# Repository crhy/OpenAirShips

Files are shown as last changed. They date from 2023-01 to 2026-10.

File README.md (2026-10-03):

# OpenAirShips
Free Travel and Total Liberty for All Humanity

All relevant information is on http://OpenAirShips.com. Pop in and join the conversation on our Discord: https://discord.gg/wZ6nu7H

OpenAirShipsLogo

## Build it: the 1026 model, v0.2.1

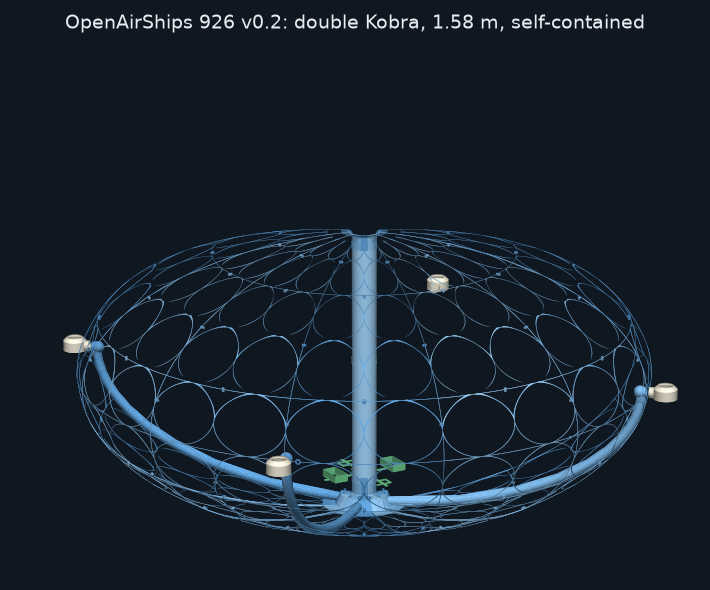
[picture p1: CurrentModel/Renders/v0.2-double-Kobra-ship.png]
OpenAirShips 1026 v0.2.1, double Kobra size, self-contained


The first buildable OpenAirShip is a 3D-printable model. It has a smooth ellipsoid hull of printed slices, a shrouded fan in a smooth central intake, and vectoring air-multiplier thrusters on the equator. Everything is open source.

### New in v0.2.1 (October 2026)
- **Flush fan housing:** each thrust duct now runs straight on from the fan housing, with no step inside or out. The ducts hug the hull curve all the way from the fan.
- **Lighter keel:** the ovals and diamonds now reach right up to the fan housing, so the hull is 4–7% lighter in every size.
- **Renamed 1026** for October 2026. The 926 files are in [`OldFiles`](OldFiles).
- **Corrected float numbers:** the v0.2 budget undercounted the double-Kobra hull (it measured 350 cm³ instead of 502). The figures below are the corrected ones, for the new, lighter hull.

### The double-Kobra build: it floats
The **double-Kobra build** is 1.58 m across. It carries its own battery and ESP32 controller and **floats on hydrogen alone**, for indoor flights in a garage or warehouse.
- **Hull:** 12 slices (4 left, 4 right, 4 plain). Each prints in 5 pieces on an Anycubic Kobra Max, and the intake shaft is two printed tubes.
- **Weight:** 977 g all-up in full-foam lightweight PLA with a 1500 mAh LiPo. Its 1022 L of hydrogen lifts 1145 g, so it has **168 g to spare**, and about 44 minutes of flight.
  - An 18650 pack gives 83 minutes, with 153 g to spare.
  - **Use full-foam LW-PLA:** in moderate foam it only just floats (+27 g with the LiPo, +12 g with the 18650 pack), and the 21700 pack makes it 93 g too heavy. See [FLOAT.md](CurrentModel/Analysis/FLOAT.md).
  - On helium (about 7% less lift) the full-foam LiPo build still floats, with about 84 g to spare.
- **Downloads:**
  - [Print files: 15 hull pieces + 2 intake tubes](CurrentModel/Print%20Files/v0.2.1%20double%20Kobra)
  - [Propulsion and avionics tray STLs](CurrentModel/CAD%20Files/Propulsion/4T/small/12s/x3.8/print)
  - [Build notes](CurrentModel/CAD%20Files/SimplifiedSlice/README.md#v02-double-kobra-build-x38-158-m-12-slices-in-pieces)
  - [Self-contained electronics](CurrentModel/Electronics/README.md#v02-self-contained-build-no-tether)
  - [BOM changes](CurrentModel/Electronics/BOM.md#v02-self-contained-double-kobra-build-changes-to-the-list-above)

### Bench and Kobra Max models (tethered)
| | 8 thrusters | 4 thrusters |
|---|---|---|
| **Bench size, 415 mm** (Prusa MK3S+) | [PieSlice1026-v0.2.1-8T.stl](CurrentModel/Print%20Files/PieSlice1026-v0.2.1-8T.stl), print 8 | [left](CurrentModel/Print%20Files/PieSlice1026-v0.2.1-4T-left.stl) and [right](CurrentModel/Print%20Files/PieSlice1026-v0.2.1-4T-right.stl), print 4 of each |
| **Kobra Max size, 790 mm** (Anycubic Kobra Max) | [PieSlice1026-v0.2.1-8T-KobraMax.stl](CurrentModel/Print%20Files/PieSlice1026-v0.2.1-8T-KobraMax.stl), print 8 | [left](CurrentModel/Print%20Files/PieSlice1026-v0.2.1-4T-left-KobraMax.stl) and [right](CurrentModel/Print%20Files/PieSlice1026-v0.2.1-4T-right-KobraMax.stl), print 4 of each |
| **Propulsion parts (STL)** | [bench](CurrentModel/CAD%20Files/Propulsion/print) · [Kobra Max](CurrentModel/CAD%20Files/Propulsion/x1.9/print) | [bench](CurrentModel/CAD%20Files/Propulsion/4T/print) · [Kobra Max](CurrentModel/CAD%20Files/Propulsion/4T/x1.9/print) |
| **Expected thrust** | ≈ 408 gf | ≈ 422 gf |

These don't float on hydrogen alone, but they can hover on their fan. The 4-thruster Kobra Max model in full-foam lightweight PLA (503 g, 124 L of hydrogen) has 55 g to spare, and the 4-thruster bench model in full foam (368 g) has 73 g.

| | |
|---|---|
| **CAD (FreeCAD, STEP, parametric Python)** | [Hull slices](CurrentModel/CAD%20Files/SimplifiedSlice) · [Propulsion](CurrentModel/CAD%20Files/Propulsion) |
| **Bill of materials** | [Electronics/BOM.md](CurrentModel/Electronics/BOM.md): about $230–320 for the core parts, with Amazon links, a lightweight-PLA option and the v0.2 changes |
| **Build notes** | [Hull slice](CurrentModel/CAD%20Files/SimplifiedSlice/README.md) · [Propulsion](CurrentModel/CAD%20Files/Propulsion/README.md) · [Electronics and firmware](CurrentModel/Electronics/README.md) |
| **Engineering** | [Will it float?](CurrentModel/Analysis/FLOAT.md) · [Airflow](CurrentModel/Analysis/AIRFLOW.md) · [Airflow, 4 thrusters](CurrentModel/Analysis/AIRFLOW-4T.md) · [Design constraints](CurrentModel/DESIGN-CONSTRAINTS.md) · [Open questions](CurrentModel/OPEN-QUESTIONS.md) |
| **Changelog** | [v0 → 1026 v0.2.1](CurrentModel/CHANGELOG.md) |

<p>
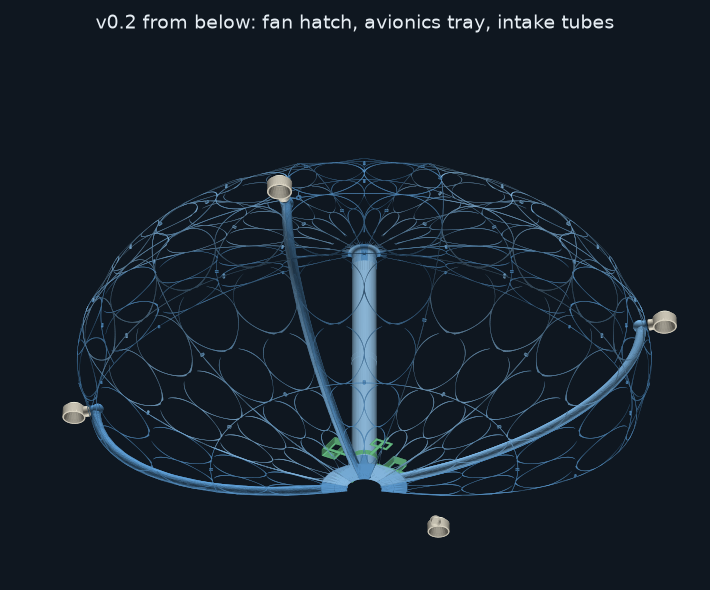
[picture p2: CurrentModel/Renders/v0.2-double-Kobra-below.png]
v0.2 from below: fan hatch, avionics tray, intake tubes

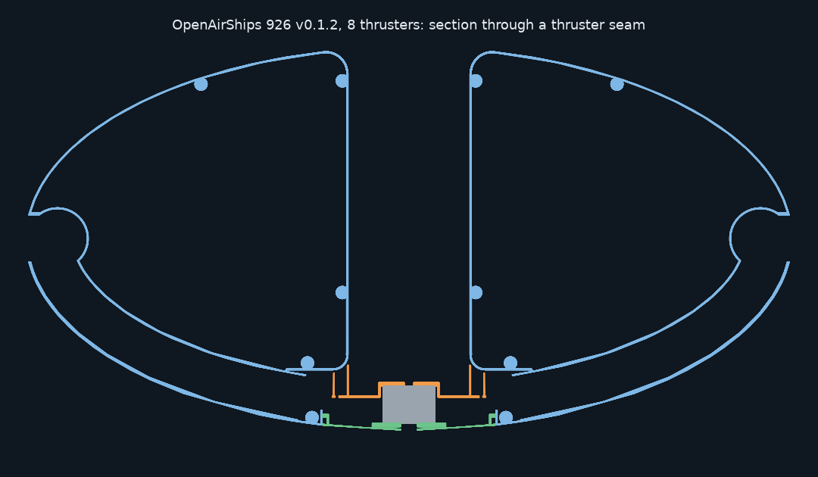
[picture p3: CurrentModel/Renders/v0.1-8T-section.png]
8 thrusters, section through a seam

</p>

**At a glance**
- **Hull:** 0.86 mm airtight walls. The outside is a smooth ellipsoid, and it's lattice everywhere except the air path. The intake is Ø66 from the bellmouth down to the fan.
- **Fan:** a 2207 1750 KV motor on 4S drives an 88 mm PETG impeller, and the hull's housing wall is its shroud. It comes out through a bayonet hatch in the keel.
- **Thrusters:** 8 or 4, each swivelling ±90° on a micro servo, exactly on the equator.
- **Control:** an ESP32 with a Wi-Fi control page and a link-loss failsafe. It drives a PCA9685 on the bench models, or the servos and ESC directly on v0.2, with a battery monitor.

## Repository layout
| Folder | What's in it |
|---|---|
| [`CurrentModel/`](CurrentModel) | **The current buildable model (1026 v0.2.1):** CAD, print files, propulsion, electronics, firmware, analysis and [changelog](CurrentModel/CHANGELOG.md) |
| [`web/`](web) | Source for [OpenAirShips.com](http://OpenAirShips.com) (static site on Cloudflare) |
| [`docs/`](docs) | Project notes: website deployment and content audit, the Unreal diagnostic report |
| [`WhitePaper/`](WhitePaper) | Whitepaper and builder guide |
| [`Art/`](Art), [`vidz/`](vidz) | Logos, concept art and concept videos |
| [`WebSnap2024/`](WebSnap2024) | PDFs of the 2024 website |
| [`OldFiles/`](OldFiles) | Earlier models and print files, kept for history |

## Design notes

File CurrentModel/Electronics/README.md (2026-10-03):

# Electronics: 1026 model (tethered bench demo and self-contained build)

- **Parts list:** [BOM.md](BOM.md), with Amazon links.
- **Firmware:** [`firmware/airship_bench`](firmware/airship_bench).

## Wiring

```mermaid
flowchart LR
  PSU["4S LiPo 1500 mAh (or 15 V 350 W supply)"] -->|"+14.8 V"| FUSE["30 A inline fuse"]
  FUSE -->|"≤ 30 cm, 12 AWG"| XT["XT60 on the ship"]
  XT --> ESC["45 A BLHeli_S ESC"]
  XT --> UBEC["5 V 5 A UBEC"]
  ESC -->|"3 phase wires"| MOTOR["2207 1750 KV + impeller"]
  ESC -->|"BEC 5 V + GND"| ESP["ESP32 DevKitC: 5V / GND pins"]
  UBEC -->|"5 V servo rail"| PCA["PCA9685: V+ terminal"]
  ESP -->|"3V3 -> VCC, GPIO21 -> SDA, GPIO22 -> SCL, GND"| PCA
  PCA -->|"ch 0-7"| SERVOS["8 x MG90S swivel servos"]
  PCA -->|"ch 8, signal + GND only"| ESC
```

- **Common ground:** tie together the grounds of the ESC, the UBEC, the ESP32 and the PCA9685.
- **ESC red wire:** pull the red (BEC +5 V) pin out of the ESC's signal plug before it goes on PCA9685 channel 8. The ESC's BEC powers the ESP32 through separate leads, and the red wire would otherwise feed into the servo rail.
- **Separate supplies:** the servos run from the UBEC. The ESP32 and the PCA9685 logic run from the ESC's BEC, so servo stalls can't brown out the ESP32.
- **Thruster numbering:** thruster *i* is on seam *i*, at azimuth 22.5° + 45° × *i*, counter-clockwise from +X seen from above. It plugs into PCA9685 channel *i*.
- **Wire routing:**
  - **Motor wires:** nothing may cross the intake shaft. The three phase wires leave through the Ø6 hole in the fan hatch. Seal the hole around the wires (hot glue or silicone, so the hatch can still come off).
  - **Motor direction:** the impeller must turn **counter-clockwise seen from above**. The bayonet hatch also relies on that direction to stay locked. If it runs the wrong way, swap any two motor wires.
  - **Servo leads:** the servos sit inside the hull, between the skin and the shaft. That space isn't part of the air path, so run the leads along the ribs and out through a lower lattice window to the electronics on the bench.
  - **Electronics:** for the tethered bench demo the ESP32, PCA9685 and UBEC ride on the bench, not in the ship; there are no decks in the bench model. The ESC sits on the test stand just under the keel, next to the hatch, so the phase wires stay short.
  - **Battery leads:** keep the battery within about 30 cm of the ESC. For a longer tether, solder a 470 µF / 35 V low-ESR capacitor across the ESC's power input.

## Power budget

| Load | Typical | Peak |
|---|---|---|
| Fan (2207 1750 KV + 88 mm impeller) | ~75 W at the firmware's 60 % cap | ~340 W (~25 A at 14.8 V) at full throttle |
| 8 × MG90S | 1–1.5 A at 5 V | 5.6 A at 5 V if all stall (the UBEC limits this) |
| ESP32 + PCA9685 | 0.25 A at 5 V | 0.5 A |

- **Power source:** a 4S LiPo (1300–1800 mAh, 75C or better) is the simplest source that handles 25 A. At full throttle it runs about 3 minutes, which is plenty for thrust runs.
- **Mains alternative:** a 15 V 350 W supply (≈23 A). Keep the firmware's `THROTTLE_LIMIT` at 0.9 or below with it.
- **Don't use 12 V:** the fan needs about 15,700 rpm, and a 1750 KV motor only reaches that on 4S (see [../Analysis/AIRFLOW.md](../Analysis/AIRFLOW.md)).

## v0.2 self-contained build (no tether)
The double-Kobra build carries everything on the avionics tray, above the fan housing and outside the gas cells. The parts are in [BOM.md](BOM.md) (items S1–S9).

```mermaid
flowchart LR
  BAT["2 x 2S 18650 packs in series (4S, 2.8 Ah), or a 4S LiPo 1500"] --> SW["power switch / XT30 loop key"]
  SW --> ESC["30 A ESC"]
  SW --> BEC["3 A BEC, 5 V"]
  SW -->|"100k / 22k divider"| ADC["ESP32 GPIO 34"]
  ESC --> MOTOR["2207 motor + impeller"]
  BEC --> ESP["ESP32 5V pin"]
  BEC --> SERVOS["4 x SG90 (5 V)"]
  ESP -->|"GPIO 25, 26, 27, 14"| SERVOS
  ESP -->|"GPIO 13, signal + GND"| ESC
  ESP -->|"I2C 21 / 22"| IMU["GY-91 IMU + baro"]
```

- **Firmware:** before building `airship_bench.ino`, add these three lines at its top:
  ```
  #define OAS_DIRECT_PWM
  #define OAS_THRUSTERS 4
  #define OAS_FIRST_AZ_DEG 15.0f
  ```
  - The ESP32 then drives the servos (GPIO 25, 26, 27, 14 for thrusters 0–3) and the ESC (GPIO 13) itself at 50 Hz, with no PCA9685.
  - The thrusters are on the left/right seams at 15°, 105°, 195° and 285°.
- **Battery monitor:** a 100 kΩ / 22 kΩ divider from the battery + to GPIO 34 (and GND).
  - Below 3.4 V per cell the firmware stops the fan and centres the servos, and it stays stopped until reset.
  - The control page shows the pack voltage.
- **ESC red wire:** as on the bench, pull it from the ESC's signal plug. The BEC powers the ESP32 and servos.
- **Wiring:** run the leads along the ribs outside the gas cells. Nothing crosses the intake tubes.
- **Hydrogen indoors:**
  - Keep every connector and switch outside the gas cells, and fill and vent the cells outdoors or with good ventilation.
  - **Helium works too:** it lifts about 7% less, 1061 g instead of 1145 g. The full-foam build with the LiPo still floats on it, with about 84 g to spare.
- **Flight time:** 44 min on the 1500 mAh LiPo, 83 min on the 18650 pack, at 24 W average. See [FLOAT.md](../Analysis/FLOAT.md).

## Bench bring-up
1. **Flash the firmware.**
   - Install the ESP32 board package and the "Adafruit PWM Servo Driver Library".
   - Open `firmware/airship_bench/airship_bench.ino` and flash it to the "ESP32 Dev Module".
2. **Check the servos with the impeller off.**
   - Join Wi-Fi "OpenAirShip" (the password is in the sketch; change it) and open http://192.168.4.1.
   - All 8 servos should centre, with lift at +1 and every jet pointing down.
   - Move the Yaw slider: every thruster should tilt the same way.
   - Set per-servo trim in `SERVO_TRIM_DEG`.
3. **Calibrate the ESC (impeller off).** Follow its manual: throttle high at power-on, then low. The firmware sends 1000–2000 µs.
4. **First spin (impeller on).**
   - Press ARM and raise the throttle slowly.
   - The firmware caps the throttle at 60 % (`THROTTLE_LIMIT`) until the impeller has been spun up and checked.
   - The fan stops on STOP, or within 1 s if the page loses its link.
5. **Measure.**
   - Put the ship on a kitchen scale: the weight drop is the lift.
   - With the optional sensors (BOM items 17–18), log plenum pressure and power against throttle.

## Firmware
- **`mixer.h`:** turns lift, surge, sway and yaw commands into swivel angles, for 8 thrusters or (with `OAS_THRUSTERS 4`) 4. All thrusters share one scale, so a yaw command gives no surge or sway. Every thruster pushes with about the same force because they share one fan, so the mixer steers direction only; the throttle sets magnitude.
- **Host test:** `g++ -std=c++17 -Iairship_bench test/test_mixer.cpp && ./a.out`, run from `firmware/`. It checks pure lift, yaw, surge, sway, the ±90° limits and the servo pulses. All of these pass.
- **`airship_bench.ino`:** the Wi-Fi access point, the control page, ESC arming and the link-loss failsafe. It has been compiled on a PC against stand-ins for the Arduino APIs, **but not yet built or run on a real ESP32**.

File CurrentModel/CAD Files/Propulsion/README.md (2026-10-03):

# Propulsion: shrouded fan, thrust ducts and air-multiplier thrusters (1026 v0.2.1)

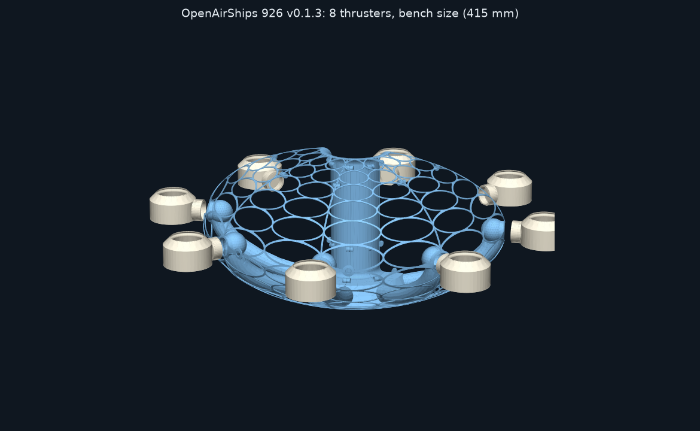
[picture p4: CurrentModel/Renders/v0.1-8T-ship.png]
8 thrusters

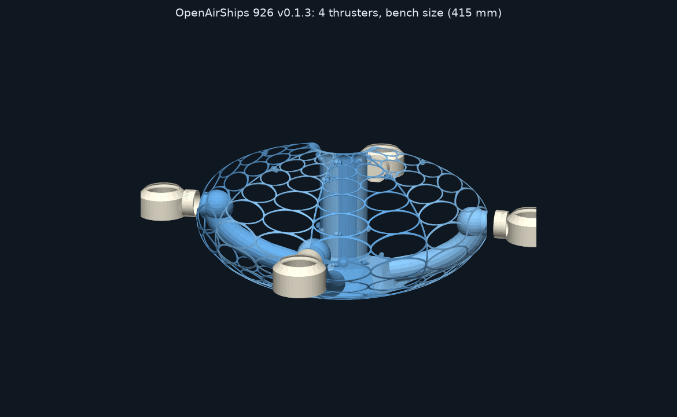
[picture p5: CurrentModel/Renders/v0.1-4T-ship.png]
4 thrusters

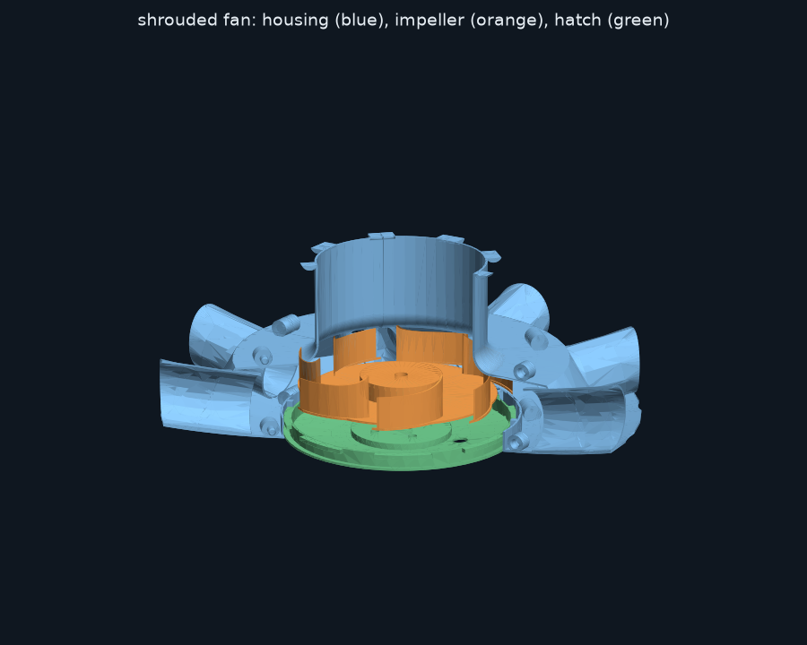
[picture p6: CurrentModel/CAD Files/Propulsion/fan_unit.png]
shrouded fan unit

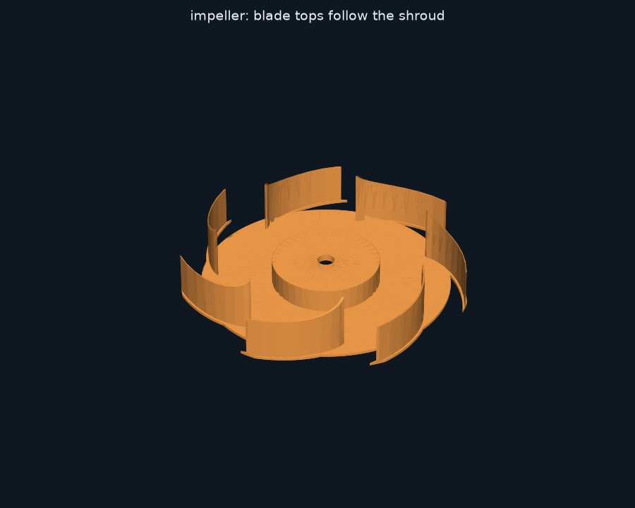
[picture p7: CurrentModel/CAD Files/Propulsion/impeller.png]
impeller

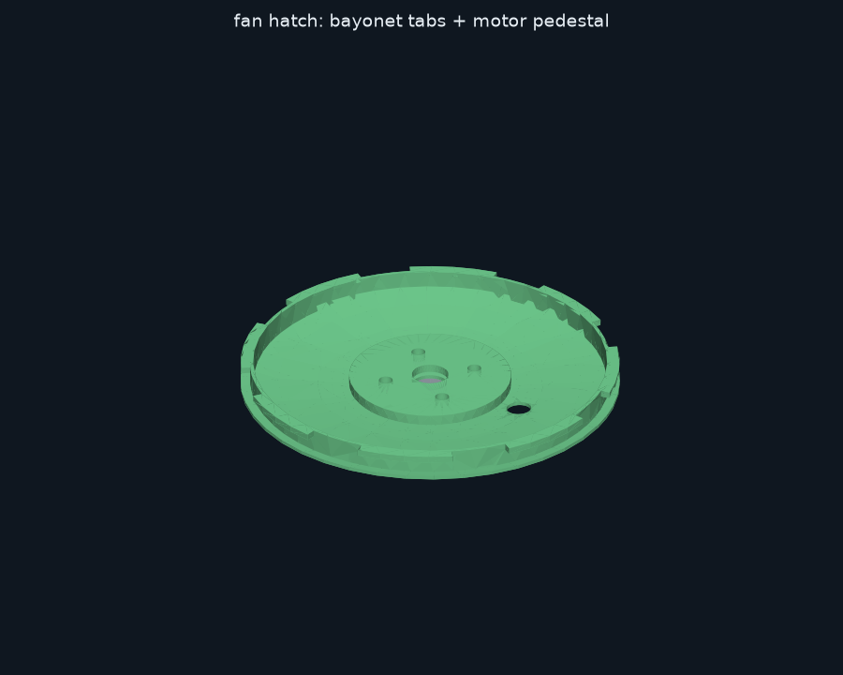
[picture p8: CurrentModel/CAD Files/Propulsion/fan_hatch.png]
fan hatch

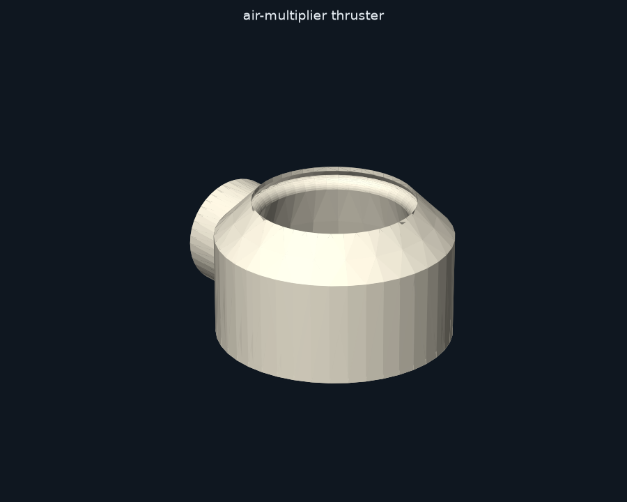
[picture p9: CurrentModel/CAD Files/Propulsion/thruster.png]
thruster


## Versions
The same parametric source (`propulsion.py`) builds the parts for every hull version. Set the version with `OAS_VARIANT=8T|4T` and `OAS_SCALE=1|1.9`, as for the slices.

| Version | Folder | Thrusters | Duct / stem | Ring | Gears | Expected thrust |
|---|---|---|---|---|---|---|
| 8 thrusters, bench | `.` (this folder) | 8 | Ø24 / Ø25-22 | 64 mm OD, 1.6 mm slot | 36T m1 | ≈ 408 gf |
| 4 thrusters, bench | `4T/` | 4 | Ø34 / Ø34-31 | 69 mm OD, 2.0 mm slot (same profile as 8T) | 44T m1 | ≈ 422 gf |
| 8 thrusters, Kobra Max | `x1.9/` | 8 | as 8T | as 8T | as 8T | ≈ 401 gf |
| 4 thrusters, Kobra Max | `4T/x1.9/` | 4 | as 4T | as 4T | as 4T | ≈ 418 gf |
| **v0.2 double Kobra** (x3.8, 12 slices) | `4T/small/12s/x3.8/` | 4 | as 8T (Ø24 / Ø25-22) | as 8T | as 8T | ≈ 306 gf |

- **4 thrusters:** each duct carries twice the flow, so the ducts, stems and rings are sized up to keep the air speeds down (see [AIRFLOW-4T.md](../../Analysis/AIRFLOW-4T.md)). Otherwise the parts and the assembly are the same as for 8 thrusters, with half as many.
- **Kobra Max size:** the fan, thrusters and servos keep their size. Only the hull grows, so the servo mount and fan hatch follow the flatter hull curve, and the ducts get longer.
- **v0.2 double Kobra:** 4 thrusters with the 8-thruster hardware, SG90 servos, a 12-tab fan hatch and the **avionics tray** (`avionics_tray.step`, 24 cm³).
  - **Tray:** a ring clamps round the lower intake tube just above the fan housing, with 4 arms reaching out between the ducts. Two arms carry battery cradles (40 × 70 × 20 mm, one 2S pack each, opposite each other for balance). The other two carry plates for the ESC, ESP32, BEC and IMU.
  - **Why the fan and ducts aren't scaled up:** the ship floats on hydrogen, so the fan only manoeuvres it. 306 gf moves the 1.58 m hull at about 2.5 m/s, which is plenty indoors. The 4-thruster Ø34 ducts would add about 60 g of duct wall. A bigger fan would add more again: motor, ESC, battery current and a wider shaft.
  - **To scale it up later:** set `OAS_THRUSTER=L` for the Ø34 ducts, stems and 69 mm rings. The fan is set by `IMP_R` / `SHAFT_R`.
  - Build it with the v0.2 settings in the slice README, plus `python3 propulsion.py`.
- **Assembly:** a 4-thruster hull alternates left and right slices. Each left/right pair closes one duct, and its right slice carries the servo hole.

## How the air moves
1. The impeller pulls air in over the bellmouth at the top of the hull and **down the smooth central shaft**. Nothing sits in the shaft: the motor stands on the fan hatch in the keel, under the impeller.
2. The shaft is the impeller eye's diameter (Ø66) all the way down. At the bottom the hull's own housing wall curves over the blade tips with 1.5 mm clearance, so the **housing acts as the fan's shroud**. The impeller throws the air outward into the housing, and it can't leak back up the shaft.
3. The housing feeds the **8 thrust ducts**, which run *inside* the skin to the equator. The hull's outside stays smooth.
4. At each thruster seam a rotating **stem** passes through a round hole in the skin. Its flange sits behind a bearing sleeve inside the duct, and it carries a printed **air-multiplier ring** with a Coanda lip and a 1.6 mm slot (2.0 mm on 4 thrusters).
5. An MG90S servo **inside the hull** turns the stem through a 1:1 pair of 36-tooth gears just outside the skin, giving ±90° of travel. The thrusters sit exactly on the equator. Their swivel axis is radial, so each jet can point anywhere between up/down and sideways along the hull. Together the thrusters give lift, yaw, surge and sway.

Expected thrust (8 thrusters): **about 4.0 N (≈ 410 gf)** at 15,650 rpm, 62 L/s. The range is 306–564 gf depending on the fan efficiency and air-multiplier gain measured on the bench; see [../../Analysis/AIRFLOW.md](../../Analysis/AIRFLOW.md).

## Parts
Print from the version's `print/*.stl`. Each file is already posed for printing: 0.2 mm layers, 0.4 mm nozzle. The table gives the 8-thruster bench sizes; 4-thruster rings are 19.8 cm³, stems 4.9, gears 2.4 and 4.8, and the fan hatch 11.3.

| Part | Qty | cm³ each | Print notes |
|---|---|---|---|
| `impeller` | 1 | 6.2 | **PETG**; the tip runs at 72 m/s. Backplate on the bed; no supports, as the cup top bridges 31 mm. Backward-curved rotor, 88 mm, 7 blades, sized by the airflow analysis: eye Ø66, exit width 12.5 mm. The blade tops follow the housing's shroud curve. Lightened: 0.8 mm backplate, 0.86 mm blades, scalloped rim. A 0.86 mm **cup** fits over the motor bell, and its 2 mm top disc is clamped between the bell and the M5 prop nut. About 8 g. Balanced by design; still check it on a pencil. |
| `fan_hatch` | 1 | 10.1 | The keel under the fan, removable. Dish down; use **supports on build plate only**, since the dish's outside is part of the hull curve and rises 2.7 mm at the rim. It carries the motor pedestal (4 × M3 × 6, 16 × 16 mm, screwed from below), a spigot wall, 8 bayonet tabs and a Ø6 wire hole. |
| `servo_mount` | 8 | 4.3 | Plate down; no supports. Epoxy it to the inside of the skin, centred on the Ø8 servo hole. The servo drops in with its spline outward and is held by two M2 screws driven from inside the hull. |
| `stem` | 8 | 3.6 | Flange down; no supports. Put it into the stem hole from inside the half-duct **before** joining the neighbouring slice. Wrap it in PTFE tape. |
| `stem_gear` | 8 | 2.1 | Flat. Glue it on the stem's D-flat. |
| `servo_gear` | 8 | 3.8 | Hub down. Its hub reaches through the Ø8 skin hole onto the servo spline. Glue it and fix it with the servo's horn screw from outside. |
| `thruster_ring` | 8 | 14.1 | Exit down, axis vertical; no supports. Every surface faces up or overhangs 45° or less. Check the 1.6 mm slot is clear; a 1.5 mm shim works. |

- **Total printed propulsion:** about 233 cm³ (≈ 290 g of PLA) for 8 thrusters, or 154 cm³ (≈ 190 g) for 4, plus the PETG impeller (≈ 8 g). Lightweight PLA for the rings and servo mounts saves about a third of theirs; see [FLOAT.md](../../Analysis/FLOAT.md).
- **Motor:** 2207 1750 KV on 4S (≈ 32 g, ≈ 25 A at full throttle). It must spin **counter-clockwise seen from above**; swap any two motor wires if it doesn't.
- **Parametric source:** `propulsion.py`. All dimensions are at the top.
- **Fit checks:** `check_fit.py` runs 35 checks against the assembled hull, and they all pass for all four versions. They cover:
  - the impeller under the shroud (≥ 1.2 mm clearance) and its path up through the hatch opening
  - the hatch at its insert angle, at 5–15 mm below seated, and locked
  - the motor and prop nut, the stems, the servos and their mounts, the gears
  - the rings at −90…+90°, including against the neighbouring thruster

## The fan hatch (bayonet)
- Each slice carries a lug and a stop post on the ring wall round the keel opening. The hatch has 8 tabs.
- **To fit it:** turn the hatch so its tabs sit on the seams (between the lugs), push it up flush, then **turn it 11.5° clockwise (seen from above)** until the tabs hit the stop posts.
- **What holds it:**
  - The housing pressure (≈ 1,900 Pa, about 13 N on the hatch) presses the tabs down onto the lugs.
  - The motor's reaction torque is clockwise, so it pushes the tabs against the posts. The hatch can't unscrew itself while the fan runs.
- **Seal:** run a strip of tape round the outside seam.

## Assembly order
1. **Slices.** Epoxy the seams of the shaft and contraction, the housing wall, the keel round the hatch ring, and the ducts, so they are airtight.
2. **Stems and servo mounts, while the slices are still apart.**
   - Put each stem into its stem hole from inside the open half-duct, then join and epoxy the neighbouring slice. This closes the duct and traps the stem's flange behind the boss.
   - Epoxy each servo mount inside the skin over its Ø8 hole. Drop the servo in and screw it from inside.
3. **Gears and rings.**
   - Centre the servos (the firmware centres every servo at boot).
   - Mesh the gears with the ring's exit pointing **down**, then glue the ring onto the stem.
4. **Fan unit** (any time after assembly, and removable for service).
   - Bolt the 2207 to the hatch's pedestal (4 × M3 × 6 from below). Pass its wires through the Ø6 hole and seal the hole around them.
   - Put the impeller on the motor shaft: its cup sits on the bell. Fix it with the M5 prop nut and trim any shaft past the nut.
   - Offer the whole unit up through the keel opening and lock the bayonet (above). The blade tops then run 1.5 mm under the shroud.
   - This relies on the motor measuring 20 mm from mount face to bell top (`MOTOR_L`). Shim under the motor, or change `MOTOR_L` and reprint, if yours differs.
5. Wire it up as in [../../Electronics/README.md](../../Electronics/README.md).

## Known limits (to bench-test)
- **Fan efficiency:** the analysis assumes 0.42 for the shrouded housing, against 0.35 for an open impeller. Measure housing pressure and motor power against throttle and put the result into `airflow.py`. The scalloped rim lets a little air fall back into the blade passages; if pressure comes out low, try `IMP_SCALLOP_R = 44` (no scallops, +3.5 g).
- **Motor cooling:** the 2207 sits under the impeller, in the housing's airflow. Check it's warm, not hot, after a full-throttle run.
- **Swivel seal:** it's a plain bore through the skin and sleeve, with PTFE tape, and some leakage is expected. Measure it before adding an O-ring.
- **Servo height:** it depends on your MG90S. If the gear hub doesn't reach the spline, shim under the servo's tabs.
- **Air-multiplier slot:** 1.6 mm is the analysis optimum for this fan within the 75 m/s tip-speed limit. Try 1.4 or 1.8 mm (`SLOT`) and compare thrust on the scale.

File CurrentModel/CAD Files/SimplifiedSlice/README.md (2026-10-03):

# Airship pie slice 1026 (v0.2.1): 8- and 4-thruster designs, bench, Kobra Max and double-Kobra sizes

One 45° slice of the hull; eight of them plug together into the full ship. The source is one parametric file that builds every version:

| Version | Slices | Print file (in `Print Files/`) | Size | Printer |
|---|---|---|---|---|
| **8 thrusters, bench** | 8 identical | `PieSlice1026-v0.2.1-8T.stl` | 415 mm across | Prusa MK3S+ (or any 210 × 210 mm bed) |
| **4 thrusters, bench** | 4 left + 4 right, alternating | `PieSlice1026-v0.2.1-4T-left.stl`, `…-4T-right.stl` | 415 mm | Prusa MK3S+ |
| **8 thrusters, Kobra Max** | 8 identical | `PieSlice1026-v0.2.1-8T-KobraMax.stl` | 790 mm | Anycubic Kobra Max (400 × 400 × 450 mm) |
| **4 thrusters, Kobra Max** | 4 left + 4 right | `PieSlice1026-v0.2.1-4T-left-KobraMax.stl`, `…-right-KobraMax.stl` | 790 mm | Kobra Max |

It keeps the outline of `OldFiles/CAD/airship pie slice 125.FCStd` (archived at the repository root): the 207.765 × 104 mm ellipse, rebuilt as clean parametric geometry. See [../../DESIGN-CONSTRAINTS.md](../../DESIGN-CONSTRAINTS.md) for the fixed rules and [../../Analysis/FLOAT.md](../../Analysis/FLOAT.md) for weights, hydrogen volume and lift.

8 thrusters: section through a seam
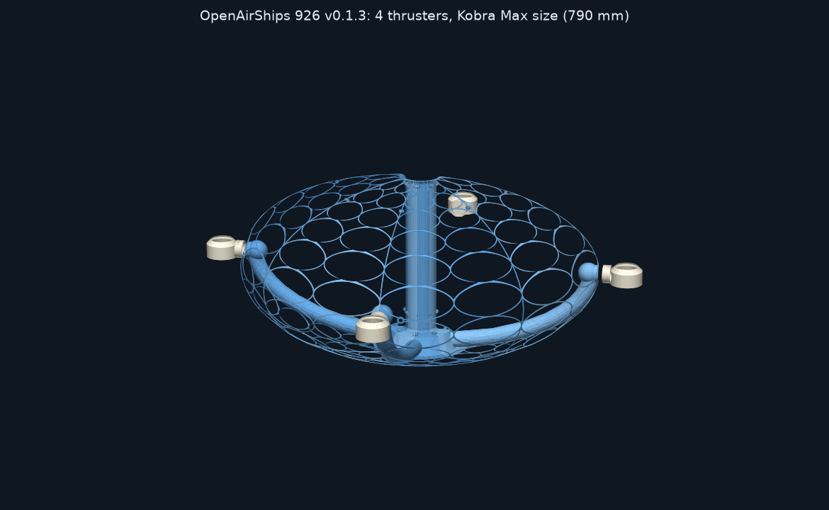
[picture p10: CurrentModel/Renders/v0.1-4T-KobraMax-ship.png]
4 thrusters, Kobra Max size

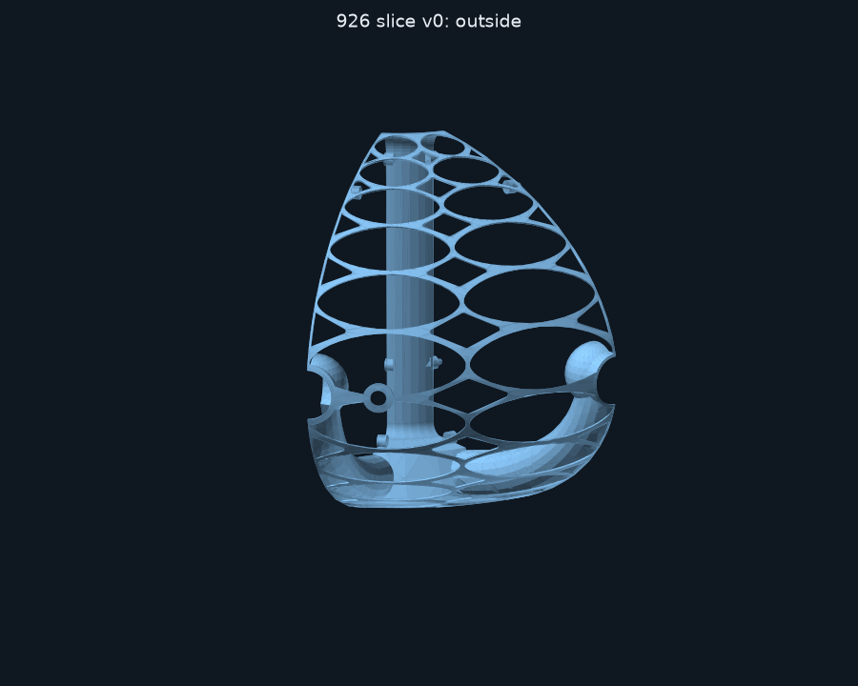
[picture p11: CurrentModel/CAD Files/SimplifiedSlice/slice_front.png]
slice, outside

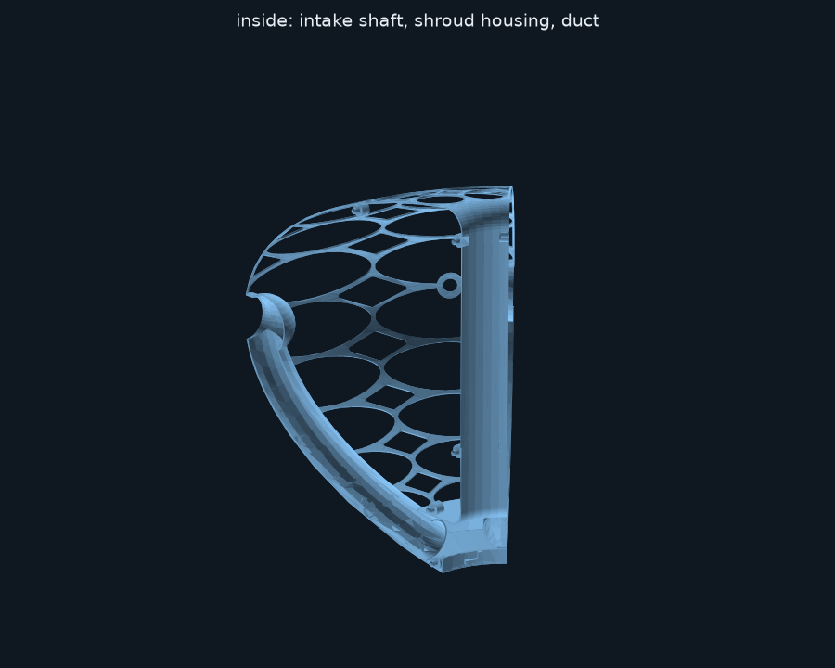
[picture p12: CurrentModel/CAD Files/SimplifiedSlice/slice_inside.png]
slice, inside

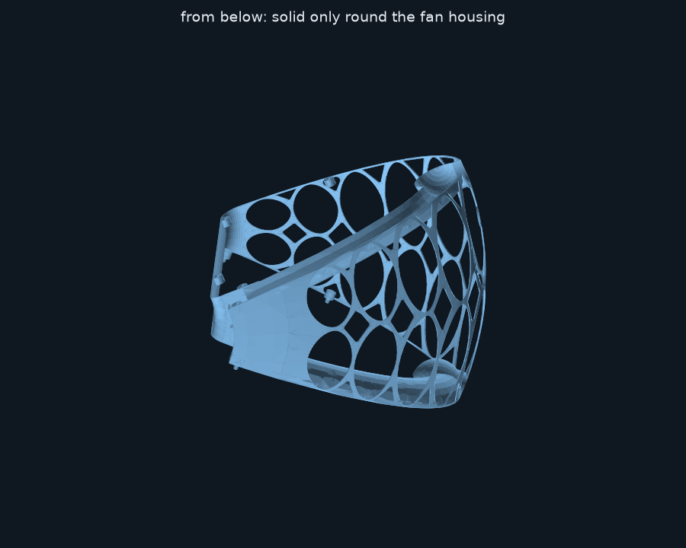
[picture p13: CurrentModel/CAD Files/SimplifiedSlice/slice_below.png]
slice from below


## What's in a slice
- **Skin:** a smooth ellipsoid outside. The skin runs in one arc from the keel up over the top and **rolls into the intake shaft over a 12 mm bellmouth**.
- **Intake shaft:** a plain 0.86 mm tube, **Ø66 all the way from the bellmouth down to the impeller eye.** Nothing is inside it: no ledge, no spider, no windows. It must stay solid and smooth for the craft's Coanda intake flow.
  - Up to v0 the shaft was Ø95 and narrowed at the bottom. That width was only needed to drop the impeller in from the top, and it now comes in through the keel hatch.
  - The narrower shaft costs about 1% of the fan pressure and gives the gas cells about 0.6 L more room.
- **Shrouded fan housing:** the housing *is* the fan's shroud.
  - At the bottom of the shaft the wall turns from axial to radial over the blade tips, with 1.5 mm clearance, and runs out flat as the housing ceiling. That's z = −71.3 for 8 thrusters, or 10 mm higher for 4 thrusters so the bigger duct mouths fit.
  - Past the blade tips the ceiling eases down to meet the ducts' tops at their mouths. The outer wall stands just past the mouths, at r = 60.5, and drops straight to the keel.
  - The keel skin is the housing's floor. Each duct hugs the hull curve from its mouth, so **it runs straight on from the housing, flush top and bottom**, with no step for the air to trip over (since v0.2.1).
  - The housing holds the impeller (r 44) and the duct mouths (r ≈ 57–60). **The keel is solid only under this housing**; from its outer wall outward it's lattice.
- **Fan hatch opening:** the keel under the fan is a Ø94 opening that the impeller and motor come in and out through. A ring wall round it carries this slice's **bayonet lug** and **stop post**. The removable `fan_hatch` (see `../Propulsion`) locks onto the 8 lugs.
- **Ducts:** they run *inside* the skin, at a constant depth along the hull curve, from their mouths in the fan housing up to the equator, where each ends in a bulb behind the stem hole and its bearing sleeve. Each duct is split by a seam plane, so two slices close it. Their own 0.86 mm walls keep them airtight; the lattice runs straight over them.
  - **8 thrusters:** Ø24 ducts on every seam, a Ø32 bulb and a Ø25.4 stem hole.
  - **4 thrusters:** Ø34 ducts on every other seam (twice the flow each), a Ø44 bulb and a Ø34.4 stem hole. A **left** slice carries its half-duct on its +22.5° seam; a **right** slice carries it on its −22.5° seam, plus the servo hole. Assemble them alternating, left, right, left, right, so each pair closes one duct.
- **Lattice:** everything else is structure only.
  - Two columns of large oval cells, with 2.0 mm ribs.
  - **Every row is the same length along the skin:** five rows from the fan housing up to the equator, six above it (about 33 mm at bench size and 73 mm at Kobra Max size). All the cells therefore have the same proportions, top and bottom.
  - A **ring rib on the equator (z = 0)** carries the thruster stem and servo holes. Thrusters stay exactly on the equator, for navigation.
  - **Minimum material:** the ovals are laid out on the real curved skin, so each fills its cell, touching all four rib lines. Every junction where ovals meet is a hollow window that takes *all* the skin more than 2 mm from the ovals, including along the first and last rows. What's left is a web of 2.0 mm ribs everywhere, and nothing thicker.
  - **Seams:** on the seams each slice's junction windows stop at a continuous 1 mm edge strip, so the two slices' strips glue into one full rib.
- **Joints:** 5 bosses along each seam, all at the same (r, z) positions. The +22.5° seam has Ø3 × 3.6 mm pegs and the −22.5° seam has Ø3.3 × 4.2 mm holes, both with 0.4 mm chamfers.

## Kobra Max size (x1.9)
- **What grows:** only the hull outline and its lattice cells grow 1.9×, to 790 mm across.
- **What stays the same size:** walls (0.86 mm), ribs (2 mm), joints, the fan, the ducts, the thrusters and the servos.
- **Why not just scale the STL:** printed mass grows about as size^1.3 while the hydrogen volume grows as size³ (124 L instead of 16 L). Scaling the STL uniformly would thicken every wall too, and the ratio would never improve.
- **Print volume:** each slice lies on its seam, 372 × 393 × 279 mm. That fits the Kobra Max's 400 × 400 × 450 mm with about 3 mm to spare each side, so **use a skirt, not a brim**, or rotate the part a few degrees on the bed.

## v0.2 double-Kobra build (x3.8, 1.58 m, 12 slices in pieces)
The self-contained build that floats on hydrogen alone. See [FLOAT.md](../../Analysis/FLOAT.md) for its weight, lift and flight time.

double-Kobra build

- **12 slices of 30°, 4 thrusters.**
  - **Left** and **right** slices each carry half a thrust duct; **plain** slices have none.
  - Go round the ship **left, right, plain**, four times.
  - Print 4 of each type.
- **Pieces:** each slice is cut into 5 pieces that fit a Kobra Max (400 × 400 × 450 mm):

  | Piece | Where | Print size (mm) |
  |---|---|---|
  | `middle` | the band z = ±150 mm round the equator, with the thruster stem hole | 187 × 307 × 395 (left), 158 × 307 × 395 |
  | `top-outer`, `bottom-outer` | the top/bottom band outside r = 415 mm | 371 × 186 × 365 |
  | `top-inner` | the top band inside r = 415, up to the bellmouth | 386 × 65 × 208 |
  | `bottom-inner` | the bottom band inside r = 415: fan housing, keel and hatch ring | 386 × 86 × 208 |

- **Joints:**
  - Every cut has a rib on it, so each piece ends in a full edge strip.
  - One Ø3 peg crosses each cut. Each seam has joints mid-way up each piece, plus the housing and keel ones.
  - Glue with CA on the lattice. Use epoxy on the housing, the keel round the hatch, the ducts and the tube sockets, which must be airtight.
- **Intake tubes:** the shaft is two printed tubes (Ø66 bore, 0.86 mm wall, 358 and 343 mm tall) instead of a wall on each slice.
  - Tube 1 sits in the socket on top of the fan housing; tube 2 goes on top of it and into the socket under the bellmouth.
  - Epoxy the sockets, since the tube is part of the air path.
- **Lattice:** 1.2 mm webs (`OAS_RIB=1.2`). The equator rib is two-sided, carrying the servo collars.
- **Thrusters:** the 8-thruster size (Ø24 ducts, Ø32 bulbs, 64 mm rings) on the 4 left/right seams.
- **Print files:** `Print Files/v0.2.1 double Kobra/`, 15 pieces (5 each for left, right and plain) plus 2 tubes, all watertight.
  - Each slice piece lies on its seam, and the tubes stand upright.
  - Print them in full-foam lightweight PLA, with the settings below.
- **CAD:**
  - `pieces/airship pie slice 1026 v0.2.1 {left,right,plain} (pieces).FCStd`, plus STEP files per piece in `pieces/<slice>/`.
  - The whole slices are in `airship pie slice 1026 4T {left,right,plain} 12s small x3.8.step`.

To regenerate:
```
export OAS_VARIANT=4T OAS_SLICES=12 OAS_THRUSTER=S OAS_PIECES=1 OAS_SCALE=3.8 OAS_RIB=1.2
for s in L R P; do OAS_SIDE=$s python3 airship_slice.py; done
freecadcmd make_pieces.py
```

## Checked (every version)
- Each part is a single valid solid, and only the 5 pegs stick out of the hull.
- Neighbouring slices overlap by 0 mm³ (for 4 thrusters: left against right, on both seams).
- **Airtight:** the keel round the hatch, the housing/shroud wall and the shaft wall are complete; their only openings are where the ducts leave the housing. The duct walls' only openings are the stem holes.
- No material sits inside the shaft or the impeller eye.
- The STLs are watertight.
- `../Propulsion/check_fit.py` passes all 35 checks for all four versions.

## Weight and volume
Weights and lift for every version and material are in [Analysis/FLOAT.md](../../Analysis/FLOAT.md).

| Version | Printed hull | PLA | Moderate-foam lightweight PLA | Full-foam lightweight PLA | Hydrogen volume |
|---|---|---|---|---|---|
| 8 thrusters, bench (8 slices) | 214 cm³ | 265 g | 171 g | 128 g | 16.5 L |
| 4 thrusters, bench (8 slices) | 184 cm³ | 228 g | 147 g | 110 g | 16.5 L |
| 8 thrusters, Kobra Max (8 slices) | 415 cm³ | 514 g | 332 g | 249 g | 124 L |
| 4 thrusters, Kobra Max (8 slices) | 349 cm³ | 432 g | 279 g | 209 g | 124 L |
| double Kobra, 12 slices (v0.2 build) | 474 cm³ | 588 g | 379 g | 284 g | 1022 L |

## Printing
- **Walls:** 0.20 mm layers, 0.4 mm nozzle, 2 perimeters, with no infill needed (the walls are 2 lines thick). Don't let "detect thin walls" change them.
- **Orientation:** every STL is already laid flat on its −22.5° seam. The skin never overhangs more than 45°. Oval tips and junction points point up, so the ribs are carried by sloping edges rather than bridges.
- **Supports:** on build plate only. Paint them inside the duct arch lying on the bed; nothing else needs support.
- **Airtight seams:** when assembling, epoxy the seams of the shaft, the housing wall, the keel round the hatch ring, and the ducts. Tape the hatch's outside seam.
- **Earlier versions:** v0 (Ø95 shaft) and revs A–D are archived in `OldFiles/PrintFiles`. RevB and revC have a duct leak, so don't print them.

### Lightweight (foaming) PLA
It saves about a third of the hull's weight; see the table above.
- **How it works:** the filament foams as it prints hotter, so you print the same lines with less plastic.
- **Airtight walls:** the shaft, housing and ducts must stay airtight. Use moderate foam (about 0.8 g/cm³) and print a small test piece of a duct first. Blow into it, or put it under water with a little air pressure.
  - If it leaks, lower the temperature and raise the flow, or brush a thin coat of epoxy inside the ducts.
- **Starting settings (MK3S+ or Kobra Max, 0.4 mm nozzle):**
  - Use the filament maker's profile if there is one.
  - Nozzle 230–245 °C for moderate foam (about 250 °C for full foam), bed 55 °C.
  - Flow (extrusion multiplier) 0.60–0.70 for moderate foam (0.45–0.55 for full foam). Calibrate on a single-wall cube to the density you want.
  - Retraction short and slow (about 0.8 mm at 25 mm/s on the MK3S+, a direct drive; 3–4 mm on the Kobra Max's Bowden), plus wipe/coast to fight stringing.
  - Part cooling 50–100%, speed 40–60 mm/s.
- **What to print in it:** the hull slices, thruster rings and servo mounts. Keep the stems, gears and fan hatch in standard PLA (accurate teeth, bearing surfaces and bayonet tabs). Keep the impeller in PETG, and never foam it: its tip runs at 72 m/s, and uneven foam would throw it out of balance.

## Files
- **FreeCAD documents:** `airship pie slice 1026[ 4T left| 4T right][ x1.9].FCStd`. Each holds the part as the base feature of a PartDesign Body, plus a parameter spreadsheet.
- **STEP:** the same parts, in the matching `.step` files.
- **`airship_slice.py`:** the parametric source (CadQuery). Everything is set at the top of the file. The version is chosen with environment variables:
  - `OAS_VARIANT=8T|4T`
  - `OAS_SIDE=L|R` (4 thrusters only)
  - `OAS_SCALE=1|1.9` (3.8 for v0.2)
  - v0.2 only: `OAS_SLICES=12`, `OAS_SIDE=P` (plain slice), `OAS_THRUSTER=S` (8-thruster-size ducts on 4 thrusters), `OAS_PIECES=1` (cut into pieces, with intake tubes), `OAS_RIB=1.2` (web width)
- **`make_pieces.py`:** builds the v0.2 piece STLs and FCStd documents.
- **`make_fcstd.py`:** builds the FCStd and the print STL for the same settings.

To regenerate, for example the right-hand 4-thruster Kobra Max slice:
```
pip install cadquery
OAS_VARIANT=4T OAS_SIDE=R OAS_SCALE=1.9 python3 airship_slice.py
OAS_VARIANT=4T OAS_SIDE=R OAS_SCALE=1.9 freecadcmd make_fcstd.py
```

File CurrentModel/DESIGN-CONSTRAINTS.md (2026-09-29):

# Design constraints (fixed rules for every revision)

These rules come from the design owner. Don't trade any of them away for weight or print time without asking first.

## Navigation
- **The thrusters sit exactly on the equator (z = 0), the vertical midpoint of the hull.** This is required for navigation: thrust at the midpoint gives yaw, surge and sway without pitching or rolling the ship. The stem/swivel axis is on the equator ring rib (`OUT_Z = 0` in `airship_slice.py`, which asserts a rib there). Don't move the thrusters up or down to shorten the ducts.

## Air path
- **The central intake shaft stays solid and smooth over its whole height.** Air drawn over the top of the hull and down the shaft gives the craft its Coanda flow, and windows or obstructions in the shaft ruin it.
  - No windows in the shaft wall.
  - Nothing inside the shaft bore: no ledges, spiders or wires. The motor stands on the fan hatch in the keel, below the fan.
  - The top of the intake is a rounded bellmouth where the hull skin rolls into the shaft. The shaft is the impeller eye's diameter (Ø66) all the way down, and at the bottom the housing wall is the fan's shroud.
- **The fan housing (plenum) and the ducts are airtight.** The keel is solid only round the fan housing, and the fan hatch closes the middle. Everywhere else the structure is lattice, and the ducts' own walls carry the air.
- **The ducts never get smaller** (Ø24 mm bore, ending in a Ø32 bulb and a Ø22 stem; Ø34 on the 4-thruster bench and Kobra Max builds). Only their walls are thinned, to the printable minimum.

## Outside shape
- **The hull's outside is a smooth ellipsoid (207.765 × 104 mm semi-axes).** The pipes and ducts run inside it. Only the thruster stems and servo gear hubs pass through round holes in the skin, and only the 5 joint pegs per slice stick out, into the neighbouring slice.

## Weight and printing (Prusa MK3S+, 0.4 mm nozzle)
- **Walls are 0.86 mm** (2 perimeters of 0.45 mm at 0.2 mm layers). That's the minimum that prints airtight, and nothing structural is thinner. Ribs are 2.0 mm wide.
- **Anything that isn't structurally essential is hollow.** The skin is two columns of large oval cells, laid out on the curved skin. Every junction is a hollow window, so every web between windows is 2.0 mm wide and nothing is thicker. The seam junctions stop short of a continuous 1 mm edge strip, so the seams stay contiguous.
- **No decks in the bench model.** The only floor is the fan-housing ceiling.
- **8 slices plug together**, with pegs on the +22.5° seam and holes on the −22.5° seam. The 8-thruster hull uses 8 identical slices. The 4-thruster hull alternates 4 left and 4 right slices, each pair closing one duct.
- **Scaling up keeps the walls thin.** A bigger hull grows its outline and lattice cells, but not its wall and rib thickness, so hydrogen volume (size³) outgrows printed mass (about size^1.3). Never scale the STL uniformly.
- **v0.2 double-Kobra build (x3.8, 12 slices).** It floats on hydrogen, flies indoors only, and puts weight before stiffness.
  - **Webs** may go down to 1.2 mm; walls stay 0.86 mm.
  - **Slices** are cut into pieces that fit the Kobra Max. Every cut lies on a lattice rib, so the edge strips stay continuous.
  - **Intake shaft:** two separate printed tubes, with the same smooth, empty Ø66 bore.
  - **Electronics:** they sit on the avionics tray round the lower intake tube, outside the gas cells and outside the air path.
- **Service:** the fan (motor and 88 mm impeller) comes out through the removable bayonet hatch in the keel.

## Scope
- The bench model is the smallest and hardest prototype to fly: lift grows with size³ and structure only with size². Hydrogen ballonets and hover are deferred to a larger model (see `OPEN-QUESTIONS.md`).

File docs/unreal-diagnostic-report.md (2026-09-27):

# OpenAirShips Unreal Diagnostic Report

Date: 2026-05-28

## Scope

This is a static repository diagnostic for the first Unreal milestone in issue #8:

- identify why the current OpenAirShips Unreal work is not reproducible from this repository,
- document the concrete blockers to opening or repairing the level,
- define a clean migration target for a 30-90 second cinematic vertical slice,
- provide a handoff checklist for the next Unreal pass.

I did not launch Unreal Engine from this repository because the repo does not currently contain an Unreal project file or source level assets that can be opened directly.

## Repository Findings

The repository currently contains brand, CAD, print, PDF, website snapshot, and rendered video assets, but not a complete Unreal project.

Relevant findings:

- There is no `.uproject` file in the repository.
- There is no Unreal `Config/`, `Content/`, `Plugins/`, `Source/`, or `Saved/Logs/` tree.
- `CurrentModel/Unreal Level` is a text handoff file with two Google Drive links: one old Unreal level and one current Unreal level.
- `CurrentModel/Blender/2024 Google Docs Link` is also an external Google Drive link rather than a versioned `.blend` source file.
- `CurrentModel/CAD Files/airship pie slice 125.FCStd` is a real FreeCAD archive and can be used as a source model candidate.
- `CurrentModel/Print Files/PieSlice1224.stl` is a real binary STL and can be used as a mesh reference.
- Several `CurrentModel/OldFiles/*` model files are 2-byte newline-only placeholders and cannot be used for migration.
- The `vidz/` folder contains rendered MP4 references. These are useful for visual direction, but they are not editable Unreal source.

## Primary Blockers

### 1. Unreal Project Is External To Git

The most important blocker is that the active Unreal level is stored as a Google Drive link instead of a versioned project folder or release artifact. This prevents contributors from knowing:

- the Unreal Engine version,
- required plugins,
- missing asset paths,
- whether the project depends on Marketplace content,
- whether any source files are absent,
- whether the project fails because of hardware scalability, plugin load errors, corrupt assets, or a bad engine association.

### 2. No Engine Version Contract

Without the `.uproject` file, there is no `EngineAssociation` value. The cleanup pass needs one explicit target, otherwise each contributor may try a different Unreal version and produce incompatible migrations.

Recommended target: Unreal Engine 5.4 or 5.5, unless the existing Drive project already has a newer valid `EngineAssociation`.

### 3. No Asset Manifest

The repo has several useful assets, but no manifest that separates:

- source assets,
- generated/exported assets,
- cinematic reference renders,
- deprecated or broken files,
- external-only assets that still need to be pulled into version control or release storage.

This makes it hard to distinguish "missing plugin" from "missing source asset" during Unreal load failures.

### 4. Laptop Load Reliability Is Undefined

The issue mentions that the level does not load reliably on a laptop. The repository has no current Unreal scalability settings, derived data cache notes, target GPU/RAM profile, or low-spec fallback map. The cinematic pass should intentionally split "working editor project" from "high-end final render."

## Recommended Clean Project Shape

Use a new clean Unreal project instead of trying to keep repairing an unknown external state.

Proposed layout:

```text
Unreal/
  OpenAirShips.uproject
  Config/
  Content/
    OpenAirShips/
      Airship/
        Meshes/
        Materials/
        Blueprints/
      Environment/
        Sky/
        Hangar/
        Platform/
        Lighting/
      Cinematics/
        Sequences/
        Cameras/
      Maps/
        OAS_Diagnostic.umap
        OAS_VerticalSlice.umap
SourceAssets/
  FreeCAD/
  Blender/
  ReferenceVideos/
Deliverables/
  screenshots/
  video/
```

Keep heavy generated files out of normal Git history unless Git LFS is configured. If Git LFS is not used, attach the Unreal source zip to a GitHub Release and store a checksum in the repo.

## Recovery Checklist

1. Download the current Unreal level from the Google Drive link in `CurrentModel/Unreal Level`.
2. Inspect the `.uproject` file before opening it:
   - `EngineAssociation`
   - `Plugins`
   - any missing module names
   - project category/template
3. Open with the matching Unreal version first. Do not auto-upgrade before saving a backup copy.
4. If Unreal reports missing plugins, classify each plugin as:
   - built-in and safe to enable,
   - Marketplace/external and unavailable,
   - unnecessary for the vertical slice and safe to remove.
5. If the project opens but is slow, immediately create `OAS_Diagnostic.umap` with only:
   - one imported airship proxy mesh,
   - one sky/atmosphere setup,
   - one platform or hangar blockout,
   - one camera rail or Level Sequence.
6. If the project does not open, migrate only usable assets into a fresh UE 5.4/5.5 project and leave the old project read-only.
7. Export a current airship mesh from FreeCAD or Blender into FBX or glTF, then import into Unreal with scale documented.
8. Create three material tiers:
   - prototype clay material,
   - brushed metal/hull material,
   - emissive window/interior accents.
9. Create a low-spec editor profile:
   - disable hardware ray tracing,
   - use scalable Lumen or baked lighting for the editor map,
   - keep Nanite only for meshes that benefit from it,
   - use proxy meshes for the first cinematic pass.
10. Save screenshots and a short viewport capture before attempting a high-quality Movie Render Queue output.

## 30-90 Second Vertical Slice Direction

The fastest credible cinematic should avoid building a full world. Build one polished scene with strong composition:

- opening shot: airship silhouette emerging from cloud/sky,
- mid shot: pass over a clean platform or hangar deck,
- hero shot: exterior airship orbit with dramatic sunlight and subtle cloud motion,
- detail shot: window/interior glow or engine/duct detail,
- final shot: pull away into open sky with logo or project title optional.

This is more achievable than a large city/world scene and directly supports the project goal: a beautiful visual direction that can attract contributors.

## Files That Need Owner Confirmation

Before a full Unreal repair pass, the owner should confirm or provide:

- current Unreal project archive from Drive,
- expected Unreal Engine version,
- whether Marketplace assets are allowed,
- license status for every non-original asset,
- whether the cinematic should prioritize realism, stylized concept art, or technical build accuracy,
- target laptop spec that must load the project,
- preferred delivery format: GitHub Release zip, Git LFS, or external asset storage plus manifest.

## Recommended Immediate Next PR

After the Drive project is available locally, the next PR should add:

- `Unreal/OpenAirShips.uproject` or a release manifest with checksum,
- `docs/unreal-asset-manifest.md`,
- `docs/unreal-open-runbook.md`,
- one screenshot proving the diagnostic map opens,
- one known-good target engine version.

That would turn the project from an external-link handoff into a reproducible Unreal collaboration target.

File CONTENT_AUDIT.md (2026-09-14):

# OpenAirShips.com migration audit

Audit date: 2026-09-12

The live Weebly site was inventoried page by page before the redesign. This document records where its public information moved. It is intentionally explicit so future edits do not silently erase project history.

| Weebly page | Preserved in the rebuild |
| --- | --- |
| Home | Low-cost housing/transport mission; small-to-large modular path; long-term power, internet, water and food horizon; DAO and uncensorable-network thesis; physical/information freedom; influences including Bitcoin, RepRap, Raspberry Pi, FarmBot, OpenStreetMap, EFF, Blender and Tor; whitepapers. See `web/index.html`, `web/open-source.html`, `web/plan.html`. |
| Plan | Eight-part original program; V1–V5 goals and every stated speed/endurance/occupancy target; hydrogen/nitrogen concept; solar, telemetry, mapping, cameras, avoidance, printer swarm and proposed material families; Santos-Dumont inspiration; high-altitude and solar-system horizons; original quotations. See `web/plan.html` and both unabridged PDFs. |
| Get Involved | Discord, GitHub, Rumble, both Blender links, both Unreal links, CAD Discord, all requested technical and organizational disciplines, original social channels, investment/crowdfunding ask, wishlist, Bitcoin, Monero, Venmo and PayPal details, funding-allocation reminder and archived media references. See `web/get-involved.html`. |
| FAQ | Hydrogen rationale and proposed safety architecture; proposed scale range; honest current progress; next steps and Harpoon Funding; cost thesis; engineering, FCC, wallet/captcha, funding and hemp obstacles; airship comparison; patent/prior-art/copyleft intent; Tesla/Elon appeal and Twitter history; “why not already”; Indiegogo, Quora and project-list references; question award. See `web/faq.html`. |
| Team | rhY, Johnnyx45, Logynn, Jodok, Kate, John, Jack, Ryan and “Could Be You,” with every published role and portrait. See `web/team.html`. |
| Hindenburg | Original anti-dismissal argument; material/coating, solvent, helium, Helium Act, management, quality-control, sabotage and blau-gas claims; technology-change analogy; 1936 Ford/Chevrolet/Plymouth/population figures; ownership/horse claim; California/New York image comparison described in the text; Quora link. Claims needing evidence are labeled rather than discarded. See `web/hindenburg.html`. |
| Open Source | Corporate/government control argument; definition and benefit of copyleft; commitment to public designs; GitHub/Discord workflow; project’s original political thesis. See `web/open-source.html`. |
| Alberto | Dates, honorific, 1899 round-trip claim, craft 1–10, No. 9 as 1903 daily driver, engine/airplane/monoplane/Wright claims, Bookshop and Wikipedia links. Disputed claims are labeled rather than removed. See `web/alberto.html`. |
| Contact | Discord, GitHub, Rumble, Freenode IRC history, old Weebly form limitation, promotional-use permission, logo variants including experimental AI art, Slashdot submission, pitch/founder video references. See `web/contact.html`. |

## Whitepapers and repository artifacts

- The 2019 whitepaper is copied without modification to `web/assets/docs/openairships-whitepaper-2019.pdf`.
- The 2026 51-page builder guide is copied without modification to `web/assets/docs/openairships-builder-guide.pdf`.
- The current printable wedge is copied to `web/assets/models/openairship-wedge.stl`.
- The source FreeCAD file remains in `CurrentModel/CAD Files/airship pie slice 125.FCStd`.
- Original art, videos, project models and repository history remain in their existing top-level folders. The redesign copies selected web-optimized assets; it does not delete the archive.

## Editorial policy used in the remodel

No historical statement was removed simply because it was abrasive, disputed or unverified. Where a statement could be mistaken for established fact, the new copy identifies it as a project claim, historic position or design target and states what evidence is missing. This keeps the information while making the public site more credible.

## Link health at migration

Links were checked on 2026-09-12. The current collaboration, donation, download, social, and crowdfunding destinations were reachable. Two historical publisher URLs—the Slashdot submission and the 2013 Popular Science item—returned 404 and 410 respectively. Both are retained as historical data and explicitly labeled in the page copy. The Internet Archive was temporarily unavailable during the audit, so archived replacements could not be confirmed. Bookshop, Indiegogo, and Quora rejected automated checks with HTTP 403; that result does not establish that their browser-facing pages are unavailable.

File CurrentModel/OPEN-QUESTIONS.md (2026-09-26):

# Open questions (after the 926 bench demo)

## 1. Flight-control code
The bench firmware (`Electronics/firmware`) maps stick commands straight to thruster angles. Flight needs these next:
- **Attitude and heading hold:** a PID loop on yaw from an IMU (BOM item 19), then altitude hold from a barometer.
- **Thrust model:** measure thrust against fan throttle and swivel angle on the scale, then fit a curve so the mixer can command forces rather than angles.
- **Buoyancy trim:** once gas is aboard, fan lift only has to cancel the error between weight and buoyancy. That changes the control design from "hover on thrust" to "trim, then manoeuvre".
- **Failsafes:** tether or link loss, low battery, a stalled servo (measure current per channel).

## 2. Hydrogen, ballonets and pressure control: deferred to a larger model
The printed 926 hull holds only 0.0188 m³ (4/3·π·0.2078²·0.104). Filled with hydrogen that lifts about **21 g** (≈1.1 kg/m³ net), against about 450 g of printed hull alone. With fixed wall thickness, lift grows with size³ but hull mass only with size². Break-even is therefore roughly 450/21 ≈ **20× this size, about 8–9 m in diameter**, before counting payload, gas cells or propulsion. So:
- **Envelope:** at larger scale the gas lives in lightweight cells inside the frame, not in the printed skin.
- **Ballonet material candidates** (to compare on cost per m², g/m², H₂ permeability, and whether they can be heat-sealed):
  - metallised BoPET (Mylar) film
  - TPU-coated nylon ripstop
  - LDPE or LLDPE film (cheapest, but permeable)
  - laminated polyethylene / EVOH barrier film
- **Pressure regulation:**
  - differential pressure sensors per cell
  - a small blower or valve per ballonet
  - relief valves sized for the maximum climb rate
- **Hydrogen safety** needs its own review: venting paths, keeping ignition sources out of gas spaces, antistatic materials, and leak detection.

These need their own design pass at the larger model's scale.

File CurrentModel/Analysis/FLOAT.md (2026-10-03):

# Will it float? Mass, hydrogen lift and fan thrust

Generated by `float_budget.py` from the current CAD (every volume comes from a tessellated STEP). Rerun it after changing the model.

**Assumptions**
- **Hydrogen:** net lift 1.12 g per litre (20 °C, sea level). The gas cells fill all the free space inside the skin, outside the shaft, fan housing and ducts.
- **Gas cells:** 12 µm LDPE film (11 g/m²), 1.3 × the hull's surface area.
- **Materials:**
  - Hull, thruster rings and servo mounts are printed in the material shown.
  - Stems, gears and the fan hatch stay standard PLA (1.24 g/cm³); the impeller is PETG.
  - Lightweight (foaming) PLA: 0.80 g/cm³ with moderate foam, 0.60 with full foam.
- **Airborne mass:** tethered, so the battery, ESC and controller stay on the bench.
- **Thrust:** the fan's full thrust with every jet pointing down, from the airflow model (2207 1750 KV on 4S, shrouded fan). The same fan at every size.
- **x1.9 (Kobra Max):** only the hull grows. Walls, ribs, fan, ducts, thrusters and servos keep their size.

| Design | Size | Hull material | Airborne mass | H₂ volume | H₂ lift | Lift ÷ mass | Fan thrust | Lift + thrust − mass |
|---|---|---|---|---|---|---|---|---|
| 8 thrusters | bench, 415 mm | PLA | 757 g | 16.5 L | 18 g | **2%** | 408 gf | -330 g |
| 8 thrusters | bench, 415 mm | LW-PLA, moderate foam | 597 g | 16.5 L | 18 g | **3%** | 408 gf | -170 g |
| 8 thrusters | bench, 415 mm | LW-PLA, full foam | 524 g | 16.5 L | 18 g | **4%** | 408 gf | -98 g |
| 4 thrusters | bench, 415 mm | PLA | 542 g | 16.5 L | 18 g | **3%** | 422 gf | -101 g |
| 4 thrusters | bench, 415 mm | LW-PLA, moderate foam | 422 g | 16.5 L | 18 g | **4%** | 422 gf | +19 g ✅ hovers |
| 4 thrusters | bench, 415 mm | LW-PLA, full foam | 368 g | 16.5 L | 18 g | **5%** | 422 gf | +73 g ✅ hovers |
| 8 thrusters | Kobra Max x1.9, 790 mm | PLA | 1065 g | 124.0 L | 139 g | **13%** | 401 gf | -525 g |
| 8 thrusters | Kobra Max x1.9, 790 mm | LW-PLA, moderate foam | 814 g | 124.0 L | 139 g | **17%** | 401 gf | -274 g |
| 8 thrusters | Kobra Max x1.9, 790 mm | LW-PLA, full foam | 700 g | 124.0 L | 139 g | **20%** | 401 gf | -160 g |
| 4 thrusters | Kobra Max x1.9, 790 mm | PLA | 786 g | 124.1 L | 139 g | **18%** | 419 gf | -228 g |
| 4 thrusters | Kobra Max x1.9, 790 mm | LW-PLA, moderate foam | 592 g | 124.1 L | 139 g | **23%** | 419 gf | -33 g |
| 4 thrusters | Kobra Max x1.9, 790 mm | LW-PLA, full foam | 503 g | 124.1 L | 139 g | **28%** | 419 gf | +55 g ✅ hovers |

- **Lift ÷ mass:** how close the hydrogen alone is to floating the model. 100% means it floats with no fan.
- **Lift + thrust − mass:** positive means the fan plus the hydrogen can hold the model up, while the fan runs.

## How big would it have to be to float on hydrogen alone?

Lift grows with size³. The thin-walled hull grows much more slowly, because its walls and ribs keep their thickness (measured below between x1 and x1.9). The fan, servos and wiring stay the same.

| Design | Hull material | Floats at scale | Hull diameter |
|---|---|---|---|
| 8 thrusters | LW-PLA, moderate foam | x4.0 (hull mass grows as S^1.03) | 1.6 m |
| 8 thrusters | LW-PLA, full foam | x3.7 (hull mass grows as S^1.03) | 1.5 m |
| 4 thrusters | LW-PLA, moderate foam | x3.5 (hull mass grows as S^1.00) | 1.5 m |
| 4 thrusters | LW-PLA, full foam | x3.2 (hull mass grows as S^1.00) | 1.3 m |

These keep today's 0.86 mm walls and 2 mm ribs. A real hull that size would need thicker ribs, or a frame and fabric envelope instead of a printed skin, so treat them as lower bounds.

## Self-contained: double Kobra size (x3.8, 1.58 m), battery and controller on board

4 thrusters on 12 slices, with the lightest printable lattice (1.2 mm webs). Each slice prints on a Kobra Max in 5 pieces, and the intake is two printed tubes. The thruster hardware is the 8-thruster size (Ø24 ducts), which keeps the duct walls light and still gives 306 gf. The fan is unchanged. The ESC, ESP32, BEC, IMU and battery are on board, on the avionics tray just above the fan housing.

Hydrogen: 1022 L, lifting **1145 g**.

| Hull material | Airframe | + electronics | Battery | Total | H₂ lift − total | Fan needed to hold height | Flight time |
|---|---|---|---|---|---|---|---|
| LW-PLA, moderate foam | 888 g | 50 g | 4S LiPo 1500 mAh, 180 g | 1118 g | **+27 g** | none: floats | 44 min |
| LW-PLA, moderate foam | 888 g | 50 g | 4S 18650 Li-ion 1P (Molicel P28A), 195 g | 1133 g | **+12 g** | none: floats | 83 min |
| LW-PLA, moderate foam | 888 g | 50 g | 4S 21700 Li-ion 1P (Molicel P45B), 300 g | 1238 g | **-93 g** | 62 W | 36 min |
| LW-PLA, full foam | 747 g | 50 g | 4S LiPo 1500 mAh, 180 g | 977 g | **+168 g** | none: floats | 44 min |
| LW-PLA, full foam | 747 g | 50 g | 4S 18650 Li-ion 1P (Molicel P28A), 195 g | 992 g | **+153 g** | none: floats | 83 min |
| LW-PLA, full foam | 747 g | 50 g | 4S 21700 Li-ion 1P (Molicel P45B), 300 g | 1097 g | **+48 g** | none: floats | 130 min |

- **Flight time** uses 80% of the battery. It counts 20 W average for manoeuvring and 4 W for the servos and electronics, plus the fan power needed to hold height when the ship is heavier than its lift.
- **Fan power to hold height:** full thrust (306 gf) takes about 370 W. Thrust grows as power^(2/3), so holding up a shortfall of W grams takes 370 W × (W / 306)^1.5.
- **Too light is fine:** a ship lighter than its lift is trimmed with a few grams of ballast, or by filling the gas cells less.

### Mass breakdown: LW-PLA, full foam, 4S LiPo 1500 mAh

| Item | g |
|---|---|
| hull (12 slices) | 285 |
| intake tubes | 76 |
| avionics tray | 14 |
| thruster rings | 34 |
| servo mounts | 13 |
| stems and gears (PLA) | 47 |
| fan hatch (PLA) | 13 |
| impeller (PETG) | 8 |
| 2207 motor | 32 |
| 4 x SG90 servos (9 g; the rings need little torque) | 36 |
| wiring | 43 |
| screws | 3 |
| glue | 65 |
| gas cells (12 um LDPE) | 77 |
| ESC 30 A (the fan peaks at ~25 A) | 7 |
| ESP32 board (drives servos and ESC directly) | 8 |
| 3 A BEC | 6 |
| IMU + barometer | 4 |
| switch, connectors, wiring | 25 |
| battery (4S LiPo 1500 mAh) | 180 |
| **Total** | **977** |
| **Hydrogen lift** | **1145** |

## Mass breakdown: 4 thrusters, Kobra Max x1.9, LW-PLA moderate foam

| Item | g |
|---|---|
| hull (8 slices) | 279 |
| thruster rings | 59 |
| servo mounts | 15 |
| stems and gears (PLA) | 60 |
| fan hatch (PLA) | 14 |
| impeller (PETG) | 8 |
| 2207 motor | 32 |
| 4 x MG90S servos | 54 |
| wiring | 24 |
| screws | 3 |
| glue | 24 |
| gas cells (12 um LDPE) | 19 |
| **Total** | **592** |

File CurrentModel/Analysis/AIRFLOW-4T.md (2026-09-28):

# Airflow: the 4-thruster design

Generated by `airflow_4t.py`, with the same fan, motor and loss model as [AIRFLOW.md](AIRFLOW.md).

With 4 thrusters instead of 8, each duct, stem and ring carries twice the flow. Keeping the air speeds the same needs twice the area:
- duct bore Ø24 → **Ø34 mm**
- stem bore Ø22 → **Ø31 mm**
- a wider slot, on a slightly larger ring

8-thruster reference: **408 gf** (duct Ø24, stem Ø22, slot 1.6 mm on a 22 mm lip radius).

| Duct Ø | Stem bore Ø | Slot lip radius | Slot | Thrust | Duct speed | Limited by |
|---|---|---|---|---|---|---|
| 24 mm | 22 mm | 22 mm | 1.6 mm | **324 gf** | 21.6 m/s | power |
| 24 mm | 22 mm | 22 mm | 2.4 mm | **284 gf** | 24.8 m/s | power |
| 30 mm | 28 mm | 26 mm | 2.0 mm | **386 gf** | 18.3 m/s | power |
| 34 mm | 31 mm | 22 mm | 2.4 mm | **422 gf** | 15.0 m/s | power |
| 34 mm | 31 mm | 25 mm | 1.6 mm | **417 gf** | 13.0 m/s | power |
| 34 mm | 31 mm | 25 mm | 2.0 mm | **422 gf** ← built | 14.6 m/s | power |
| 34 mm | 31 mm | 25 mm | 2.4 mm | **419 gf** | 16.0 m/s | power |
| 34 mm | 31 mm | 31 mm | 1.6 mm | **422 gf** | 14.6 m/s | power |

- **Keeping the 8-thruster ducts (Ø24) with only 4 thrusters loses about a fifth of the thrust.** Each duct would carry twice the flow at twice the speed, so its losses would be four times higher.
- **With the ducts and stems scaled up, 4 thrusters make slightly more thrust than 8** (about +3%). There are fewer, larger passages with less wall friction.
- **Built:**
  - duct Ø34, stem Ø34/31
  - ring with the 8-thruster ring's profile (32 mm tall, 12 mm between throat and outer wall), on a 22.5 mm throat with a 3.5 mm Coanda lip and a 2.0 mm slot (25 mm slot radius)
  - the Ø31 stem bore reshapes into an oval port of the same area where it enters the ring, so the ring can stay 32 mm tall
  - 44-tooth gears to clear the wider stem
  - a housing ceiling 10 mm higher, so the Ø34 duct mouths fit under it

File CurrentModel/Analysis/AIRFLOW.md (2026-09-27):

# Airflow analysis: impeller, ducts and air-multiplier thrusters

Generated by `airflow.py` from the current CAD dimensions. Rerun it after changing the model.

## Inputs

- Air: ρ = 1.204 kg/m³ (20 °C, sea level).
- **Ducts:** 8 × Ø24 mm, 172 mm long, with the mouth at r = 58 mm on the keel.
- **Stem bore:** Ø22 mm.
- **Air-multiplier slot:** at a radius of 22 mm, 1.6 mm wide in rev E.
- **Impeller:** Ø88 mm, eye (blade inlet) radius 33 mm, blade height 17→12 mm, running 1.5 mm under the housing's stationary shroud.
- **Coefficients (the main uncertainties):**
  - slot C_d = 0.85, C_v = 0.95
  - thrust augmentation φ = 1.3 (published Coanda ejectors: 1.1–1.6)
  - fan static pressure coefficient ψ = 0.3, fan static efficiency η = 0.42
  - motor efficiency 0.75
  - loss coefficients K: duct entry 0.5, duct bends 0.3, dead end turn 1.2, stem entry 0.5, stem dump 1.0

## 1. What would hovering take?

- **Estimated all-up mass:** 887 g (hull 390, printed propulsion 250, motor 50, servos 107, esc 25, electronics 35, wiring 30).
- **Hydrogen lift:** the 12.7 L above the main deck gives 14 g, so thrust has to carry about 873 g, i.e. 8.6 N.
- **Jet speed sets the airflow needed:** thrust is φ·ṁ·V_j and jet power is ½ṁV_j², so a slower jet needs less power but more airflow.

| Jet speed V_j (m/s) | Air flow needed (L/s) | Jet power (W) | Slot area per thruster (mm²) | Duct speed in Ø24 (m/s) |
|---|---|---|---|---|
| 15 | 365 | 49 | 3576 | 101 |
| 25 | 219 | 82 | 1287 | 60 |
| 40 | 137 | 132 | 503 | 38 |
| 60 | 91 | 198 | 223 | 25 |

**Conclusion: hovering on fan thrust isn't feasible at this scale.**
- **Slow jets:** below about 25 m/s the airflow runs to hundreds of L/s. That needs ducts of Ø60 mm or more and an impeller eye bigger than the whole shaft.
- **Fast jets:** above 40 m/s the jet power alone is over 100 W, before any losses. With fan and motor efficiency, the motor would need more than 400 W.
- **So the bench demo's job is to show controlled, vectored thrust, not to hover.**

## 2. The first design, v0 (0.8 mm slot, Ø13 stem)

| Motor | Limited by | Shaft W used | Flow L/s | Plenum pressure Pa | Jet m/s | Stem m/s | Thrust N (gf) | Fan rpm |
|---|---|---|---|---|---|---|---|---|
| A2212 1000KV, 3S | speed | 23 of 125 | 15.7 | 605 | 21 | 15 | 0.51 (52) | 8880 |
| A2212 1000KV, 4S | speed | 54 of 167 | 20.9 | 1075 | 28 | 20 | 0.91 (93) | 11840 |

Where the pressure goes (3S case):

| Item | Pa | Share |
|---|---|---|
| slot (useful: makes the jet) | 291 | 48 % |
| duct entry | 6 | 1 % |
| duct friction | 3 | 1 % |
| duct bends | 3 | 1 % |
| turn into stem | 158 | 26 % |
| stem friction | 12 | 2 % |
| stem dump into ring | 132 | 22 % |

**Findings:**
1. **Fan speed, not motor power, is the limit.** On an 88 mm open impeller, the A2212's loaded speed caps the plenum pressure (about 600 Pa on 3S, about 1,070 Pa on 4S) before the motor reaches its power.
2. **The 0.8 mm slot makes a small, fast jet** that spends its power on speed rather than on moving air.
3. **The Ø13 mm stem is a choke:** air in it moves about as fast as in the slot, so it throws away a similar amount of pressure.

## 3. Design sweep: slot width, stem bore, battery

Each row is limited by whichever runs out first: the motor's power or its loaded speed on an 88 mm impeller. The impeller eye and exit width it would need are listed too.

| Motor | Slot mm | Stem Ø mm | Limited by | Flow L/s | Plenum Pa | Jet m/s | Thrust N (gf) | Fan rpm | Eye r mm | b2 mm |
|---|---|---|---|---|---|---|---|---|---|---|
| A2212 1000KV, 3S | 0.8 | 18 | speed | 20 | 605 | 26 | 0.81 (82) | 8880 | 22 | 7 |
| A2212 1000KV, 3S | 0.8 | 22 | speed | 21 | 605 | 28 | 0.92 (93) | 8880 | 22 | 7 |
| A2212 1000KV, 3S | 1.2 | 18 | speed | 26 | 605 | 23 | 0.93 (95) | 8880 | 24 | 9 |
| A2212 1000KV, 3S | 1.2 | 22 | speed | 29 | 605 | 26 | 1.17 (119) | 8880 | 25 | 10 |
| A2212 1000KV, 3S | 1.6 | 18 | speed | 30 | 605 | 20 | 0.94 (96) | 8880 | 25 | 11 |
| A2212 1000KV, 3S | 1.6 | 22 | speed | 35 | 605 | 23 | 1.29 (131) | 8880 | 27 | 12 |
| A2212 1000KV, 3S | 2.0 | 18 | speed | 33 | 605 | 17 | 0.89 (91) | 8880 | 26 | 12 |
| A2212 1000KV, 3S | 2.0 | 22 | speed | 40 | 605 | 21 | 1.32 (134) | 8880 | 28 | 14 |
| A2212 1000KV, 3S | 2.5 | 18 | speed | 35 | 605 | 15 | 0.81 (83) | 8880 | 26 | 12 |
| A2212 1000KV, 3S | 2.5 | 22 | speed | 44 | 605 | 19 | 1.28 (130) | 8880 | 29 | 16 |
| A2212 1000KV, 4S | 0.8 | 18 | speed | 26 | 1075 | 35 | 1.44 (147) | 11840 | 24 | 7 |
| A2212 1000KV, 4S | 0.8 | 22 | speed | 28 | 1075 | 37 | 1.63 (166) | 11840 | 25 | 7 |
| A2212 1000KV, 4S | 1.2 | 18 | speed | 35 | 1075 | 31 | 1.66 (169) | 11840 | 26 | 9 |
| A2212 1000KV, 4S | 1.2 | 22 | speed | 39 | 1075 | 34 | 2.08 (212) | 11840 | 27 | 10 |
| A2212 1000KV, 4S | 1.6 | 18 | speed | 40 | 1075 | 27 | 1.67 (170) | 11840 | 28 | 11 |
| A2212 1000KV, 4S | 1.6 | 22 | speed | 47 | 1075 | 31 | 2.29 (233) | 11840 | 30 | 12 |
| A2212 1000KV, 4S | 2.0 | 18 | speed | 44 | 1075 | 23 | 1.59 (162) | 11840 | 29 | 12 |
| A2212 1000KV, 4S | 2.0 | 22 | speed | 53 | 1075 | 28 | 2.34 (239) | 11840 | 31 | 14 |
| A2212 1000KV, 4S | 2.5 | 18 | speed | 47 | 1075 | 20 | 1.44 (147) | 11840 | 29 | 12 |
| A2212 1000KV, 4S | 2.5 | 22 | speed | 58 | 1075 | 25 | 2.28 (232) | 11840 | 32 | 16 |
| A2212 1400KV, 3S | 0.8 | 18 | speed | 28 | 1185 | 37 | 1.59 (162) | 12432 | 24 | 7 |
| A2212 1400KV, 3S | 0.8 | 22 | speed | 29 | 1185 | 39 | 1.80 (183) | 12432 | 25 | 7 |
| A2212 1400KV, 3S | 1.2 | 18 | speed | 36 | 1185 | 32 | 1.83 (186) | 12432 | 27 | 9 |
| A2212 1400KV, 3S | 1.2 | 22 | speed | 41 | 1185 | 36 | 2.29 (233) | 12432 | 28 | 10 |
| A2212 1400KV, 3S | 1.6 | 18 | speed | 42 | 1185 | 28 | 1.84 (188) | 12432 | 28 | 11 |
| A2212 1400KV, 3S | 1.6 | 22 | speed | 49 | 1185 | 33 | 2.52 (257) | 12432 | 30 | 12 |
| A2212 1400KV, 3S | 2.0 | 18 | speed | 46 | 1185 | 24 | 1.75 (178) | 12432 | 29 | 12 |
| A2212 1400KV, 3S | 2.0 | 22 | power | 55 | 1148 | 29 | 2.50 (255) | 12237 | 31 | 14 |
| A2212 1400KV, 3S | 2.5 | 18 | speed | 49 | 1185 | 21 | 1.59 (162) | 12432 | 30 | 12 |
| A2212 1400KV, 3S | 2.5 | 22 | power | 59 | 1076 | 25 | 2.28 (232) | 11844 | 32 | 16 |
| 2207 1750KV, 4S | 0.8 | 18 | power | 42 | 2764 | 56 | 3.70 (377) | 18987 ✗ | 28 | 7 |
| 2207 1750KV, 4S | 0.8 | 22 | power | 44 | 2652 | 58 | 4.02 (410) | 18598 ✗ | 29 | 7 |
| 2207 1750KV, 4S | 1.2 | 18 | power | 51 | 2303 | 45 | 3.55 (362) | 17331 ✗ | 30 | 9 |
| 2207 1750KV, 4S | 1.2 | 22 | power | 55 | 2136 | 48 | 4.13 (421) | 16691 ✗ | 31 | 10 |
| 2207 1750KV, 4S | 1.6 | 18 | power | 56 | 2088 | 37 | 3.24 (331) | 16501 ✗ | 32 | 11 |
| 2207 1750KV, 4S | 1.6 | 22 | power | 62 | 1879 | 41 | 4.00 (408) | 15653 | 33 | 12 |
| 2207 1750KV, 4S | 2.0 | 18 | power | 59 | 1971 | 31 | 2.91 (297) | 16033 | 32 | 12 |
| 2207 1750KV, 4S | 2.0 | 22 | power | 67 | 1731 | 36 | 3.77 (385) | 15026 | 34 ✗ | 14 |
| 2207 1750KV, 4S | 2.5 | 18 | power | 62 | 1889 | 26 | 2.54 (259) | 15693 | 33 | 12 |
| 2207 1750KV, 4S | 2.5 | 22 | power | 72 | 1622 | 31 | 3.44 (351) | 14543 | 35 ✗ | 16 |
| 2207 2400KV, 4S | 0.8 | 18 | power | 47 | 3459 | 63 | 4.63 (472) | 21240 ✗ | 30 | 7 |
| 2207 2400KV, 4S | 0.8 | 22 | power | 49 | 3319 | 65 | 5.03 (513) | 20804 ✗ | 30 | 7 |
| 2207 2400KV, 4S | 1.2 | 18 | power | 57 | 2882 | 50 | 4.45 (453) | 19387 ✗ | 32 | 9 |
| 2207 2400KV, 4S | 1.2 | 22 | power | 61 | 2674 | 54 | 5.17 (527) | 18672 ✗ | 33 | 10 |
| 2207 2400KV, 4S | 1.6 | 18 | power | 62 | 2613 | 42 | 4.06 (414) | 18459 ✗ | 33 | 11 |
| 2207 2400KV, 4S | 1.6 | 22 | power | 69 | 2351 | 46 | 5.01 (511) | 17510 ✗ | 35 ✗ | 12 |
| 2207 2400KV, 4S | 2.0 | 18 | power | 66 | 2467 | 35 | 3.64 (371) | 17935 ✗ | 34 | 12 |
| 2207 2400KV, 4S | 2.0 | 22 | power | 75 | 2167 | 40 | 4.72 (481) | 16808 ✗ | 36 ✗ | 14 |
| 2207 2400KV, 4S | 2.5 | 18 | power | 69 | 2363 | 29 | 3.18 (324) | 17555 ✗ | 35 ✗ | 12 |
| 2207 2400KV, 4S | 2.5 | 22 | power | 80 | 2029 | 34 | 4.31 (439) | 16268 | 37 ✗ | 16 |

✗ = doesn't fit or isn't safe:
- the impeller eye must stay 10 mm inside the 44 mm rim
- the exit width is limited to 20 mm by the plenum height over the impeller
- the rim speed must stay ≤ 75 m/s for a printed impeller (PETG). The 2207 2400KV would make more thrust, but only above that speed.

## 4. Recommended design point

The best feasible combination in the sweep: **2207 1750KV, 4S**.

| | v0 | Recommended (built into rev E) |
|---|---|---|
| Air-multiplier slot | 0.8 mm | **1.6 mm** |
| Stem bore | Ø13 mm | **Ø22 mm** (stem hole in the hull grows to Ø25) |
| Duct bore | Ø24 mm | Ø24 mm along its length (duct speed 17 m/s: friction is negligible), **flared to about Ø32 mm over its last 25 mm** so the wider stem enters it cleanly |
| Impeller eye radius | 22 mm | **34 mm** (inlet speed ≤ 22 m/s) |
| Impeller exit width b2 | 9 mm | **13 mm** |
| Motor / battery | A2212 1000KV, 3S | **2207 1750KV, 4S** |
| Fan speed | — | **15653 rpm** (tip speed 72 m/s); motor shaft power used 277 W, about 25 A at 14.8 V |
| Airflow | — | 62 L/s total, 7.8 L/s per thruster |
| Plenum pressure | — | 1879 Pa |
| Jet speed | — | 41 m/s |
| **Total thrust** | — | **4.00 N ≈ 408 gf** (51 gf per thruster) |

**Uncertainty:** with φ between 1.1 and 1.6 and fan efficiency between 0.35 and 0.50, the thrust range is **306–564 gf**. Measure φ and the fan curve on the bench, then rerun.

## 5. Plenum (fan chamber) sizing

The plenum only has to carry 62 L/s from the impeller rim (r = 44 mm) out to the duct mouths (r ≈ 58 mm), keeping the radial speed under 8 m/s:

| Radius mm | Height needed mm |
|---|---|
| 44 | 28 |
| 55 | 22 |
| 65 | 19 |
| 58 | 21 |

- **Impeller height:** the recommended impeller is about 15 mm tall at the rim, so the chamber needs about that height over the impeller (r ≤ 44 mm). The current floor at z = −70 above a keel at about −101 gives 31 mm there. That's enough, so **the floor can't come down much over the impeller**.
- **Shrouded fan:** the housing is the fan's shroud. The intake shaft is the impeller eye's diameter (Ø66) all the way up. Its wall turns over the blade tips with 1.5 mm clearance and runs out as the housing ceiling. (Up to v0 the shaft was Ø95 and narrowed at the bottom; it only had to be that wide for the impeller to drop in from the top, and the impeller now comes in through the keel hatch.)
  - The narrower intake speeds the air up from about 9 to about 18 m/s. With the bellmouth that costs about 20 Pa, around 1% of the fan pressure, and it gives the gas cells about 0.6 L more room.
  - In the open design there was a 3.4 mm annulus between the impeller tip and the shaft wall, right at the housing's highest-pressure point, so housing air leaked straight back up the shaft. The shroud closes it, and air can only leave through the ducts.
  - fan efficiency 0.35: 3.55 N ≈ 361 gf
  - fan efficiency 0.42: 4.00 N ≈ 408 gf
  - fan efficiency 0.50: 4.50 N ≈ 459 gf
  - This analysis uses η = 0.42 for the shrouded housing (0.35 was the open impeller's estimate). Measure it on the bench.
- **As built (rev E):** the ceiling is flat out to r = 66 mm, then slopes down to the keel at r = 80 mm. The duct mouths sit at r ≈ 58 mm, just outside the impeller tip.
  - The keel is solid only round this housing, and a removable bayonet hatch closes the middle and carries the motor. Outside it the skin is the oval/diamond lattice; the ducts carry the air from there, and their own walls keep it airtight.
  - The intake mouth at the top is a rounded bellmouth (the skin rolls into the shaft over a 12 mm radius), which keeps the entry loss small. The shaft has no ledge or spider in it: the motor stands on the fan hatch.

## 6. What to measure on the bench

1. **Fan curve:** plenum pressure (MPXV7002DP) and motor power (INA226) against throttle, with the thrusters blanked off and then open.
2. **Thrust augmentation φ:**
   - thrust of one thruster on the scale, with the ring fitted and with a bare stem of the same flow
   - slot exit speed from a pitot tube, or from Q/A
3. **Losses:** pressure at the stem inlet against the plenum. This checks the duct and turn losses.
4. **Rerun:** put the measured coefficients into `airflow.py` and rerun it before cutting new parts.

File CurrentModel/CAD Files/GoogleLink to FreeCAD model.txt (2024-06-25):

Here's the link to the current FreeCAD model.  It's too big for github.  :(

https://drive.google.com/file/d/1bUMCxcfC8S7HnDZvkRIqjPBGFJlN2646/view?usp=sharing

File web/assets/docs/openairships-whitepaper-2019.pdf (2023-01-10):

### OpenAirShips.com

### The White Paper

Increasingly governments and corporations are limiting our ability to self-govern or even effect reasonable change in our supposedly “democratic” institutions. The censorship of dissenting voices on platforms like YouTube and reddit is almost complete, and Google has even pulled advertising of political candidates in order to manipulate US elections. Meanwhile, restrictive and fascist governments the world over are colluding with large corporations to maintain a stranglehold on the Internet, on Internet Infrastructure, and also tracking and recording the movements and activities of citizens globally effectively ending all humanity’s right to privacy, right to travel, freedom of speech and in many cases, even our right to live, grow food, obtain fresh potable water, or even raise our own families.

Regardless of advances in technology such as cryptocurrency, onion routing, and ever more sustainable and freedom focused software and hardware, the network itself is still a point of control and economic genocide.

The only way to truly combat this ever-increasing dystopian nightmare of corporate genocide is to allow the global citizenry the ability to quickly and cheaply deploy a new physical network that is decentralized, untrackable, incentivized, and impossible to control or manipulate by bad actors, primarily the existing power structures that stand to lose control: The IMF, World Bank, UN, US Empire, Verizon, Charter, Google, Amazon, and all the other corporations and governments colluding with them to continue to dominate and manipulate all human commerce and life.

Through Open Source, Low Cost 3d Printing, advanced blockchain and p2p mesh networking, we believe OpenAirShips.com has a potential solution to truly free humanity from all previous forms of fascism and genocide.

### The Network

The network will consist of a wireless p2p mesh network of highly secure blockchain encrypted real-time frequency switching ultra wideband radio hardware offering an incentivized blockchain based high bandwidth and long distance peer to peer network that is truly decentralized, infinitely scalable, uncensorable, and untrackable.

In order to understand where UWB fits in with the current trends in wireless communications, we need to consider the general problem that communications systems try to solve. Specifically, if wireless were an ideal medium, we could use it to send
1. a lot of data,
2. very far,
3. very fast,
4. for many users,
5. all at once.
Unfortunately, it is impossible to achieve all five attributes simultaneously for systems supporting unique, private, two-way communication streams; one or more have to be given up if the others are to do well. Original wireless systems were built to bridge large distances in order to link two parties together. However, recent history of radio shows a clear trend toward improving on the other four attributes at the expense of distance. Cellular telephony is the most obvious example, covering distances of 30 kilometers to as little as 300 meters. Shorter distances allow for spectrum reuse, thereby serving more users, and the systems are practical because they are supported by an underlying wired infrastructure– the telephone network in the case of cellular. In the past few years, even shorter range systems, from 10 to 100 meters, have begun emerging, driven primarily by data applications.

-From Ultra-Wideband Technology for Short- or Medium-Range Wireless Communications Jeff Foerster, Intel Architecture Labs, Intel Corp. Evan Green, Intel Architecture Labs, Intel Corp. Srinivasa Somayazulu, Intel Architecture Labs, Intel Corp. David Leeper, Intel Connected Products Division, Intel Corp.

Currently UWB has been monopolized and restricted by the FCC in the US, making it all but worthless as a networking technology. Our decentralized peer to peer network will be illegal in the US and a form of civil disobedience from the outset.

Civil Disobedience FOR PROFIT.

### The BlockChain

The Blockchain that will be developed to operate and incentivize this network will have the following capabilities:

Mineable through network hop data transfer.

Mineable through network database storage and access.

Mineable through deployment of new hardware (nodes) on the network.

Mineable through development of the technology and infrastructure that is ratified and approved by the open source community.

Mineable through provision of 3d and image data of the surrounding area.

Mineable for providing transportation (Replacing UPS, Amazon, Uber, et al).

Mineable for providing housing (Replacing AirBNB, et al).

Mineable for providing 3d printing services.

Mineable for providing fresh water, sewage treatment, electricity, organic heirloom food, organic heirloom seeds, organic hemp based sustainable 3d printing filament.

Mineable through other smart contracts agreed to by parties on the network.

Mineable through staking, masternodes, and helping to secure the network by verifying transactions.

Mineable by providing text, video, and images to the network.

Mineable by providing an audience for any entity hoping to promote their own media.

Mineable by offering real time exchange of other goods, services, and also exchanging other assets and cryptocurrencies.

Mineable by offering education and providing hardware to new nodes.

Mineable by offering new governance suggestions that are adopted by the network.

Mineable by voting for governance proposals.

The Blockchain will be completely privacy focused, impossible to mine as proof of work, and loosely based on existing blockchain masternode technology, such as Pivx, Social Send, Vitae, or Neutron.

### Why AirShips?

AirShips offer the most efficient way to distribute hardware quickly and cheaply on a truly global scale. By operating on a buoyancy principle, the AirShip does not require energy to provide lift, but can maintain it’s elevation by decompressing or compressing hydrogen real time, into and out of ballonets and pressurized tanks. Because hydrogen is explosively reactive with oxygen, which is abundant in our atmosphere, the hydrogen systems will be kept in an oxygen-free nitrogen gas environment, as is commonly done in commercial hydrogen systems now.

By operating as an actively mobile node, the network will be uncensorable globally by operating as a real time infiltration of a truly free network that is beyond government or corporate control. Even in areas where a government or corporation have captured or destroyed nodes, new nodes will quickly move in to fill the gaps as the network is incentivized via blockchain reward. The more destructive the environment, and the more AirShips have been lost in a locality, the higher the blockchain reward for that network region. Incentivizing aggressive destruction of censorship and fascistic control of airspace or radio spectrum.

Larger AirShips can also provide transportation away from fascist and corporate properties and regions both over land and water. Ensuring that people in that region can escape war, famine, or other debilitating forms of genocide that are usually the result of economic factors driven by traditional power structures we are aiming to rapidly supplant. Furthermore, large AirShips can provide real-time emergency housing for people displaced by violence or natural disaster.

### The AirShips

Materials:

Hydrogen is the most abundant element in the universe. Hydrogen in it’s purified gas form is lighter than air or any other gas, allowing for free transport to any altitude in any atmosphere. Water covers most of the earths surface. Hydrogen can be extracted from water by electrolysis, which can be done using solar power.

Carbon is the 12th most abundant element on earth, and can be freely harvested from the air as Carbon Dioxide, a greenhouse gas that is currently at a higher atmospheric concentration than what climatologists feel is ideal. Carbon can be used to make carbon fiber, a very strong and light structural material. Carbon can also be used to make Graphene, one of the strongest materials known to man, and an excellent conductor. Graphene can also be used to make extremely energy-dense ultracapacitors, and also carbon nanotube based solar cells, which are an extremely efficient type of photovoltaic.

Nitrogen is the 5th most abundant element in the universe, and can freely harvested directly from the atmosphere. Nitrogen will be used to encapsulate the hydrogen ballonets and compressed hydrogen storage in order to prevent an explosive reaction between hydrogen and oxygen.

Design:

The AirShip design will be highly modular. A circular design means that each section of the structure is homogeneous. This will lead to low-cost mass production, and also simplify and speed iterative design. This will also lead to higher safety, as any failure of any single section will not compromise the stability or operation of the entire craft.

The design will be open source. This will ensure that engineers all over the world will submit rapid improvements and design iterations. This will also ensure the lowest possible cost for acquisition globally.

Each structural and mechanical piece should be designed with the goal of being 3d printable by anyone who already owns an airship. Allowing for iterative upgrades.

The actual networking and operation will be handled by low cost open source hardware, such as the raspberry pi. By having a pi in each section of the AirShip and operating them as a cluster, utilizing the open source ProxMox virtualization container as a template, we will ensure that even in a catastrophic event, some part of the operating system will always be running.

The AirShip will have a Sun Deck at the top, and a spiral staircase from the sun deck down to the main living area, and also continuing down to exit the bottom of the AirShip.

The bottom of the Spiral Staircase will be retractable during flight, and also for security.

Traversal from one AirShip to another will be effortless by exiting the bottom of the AirShip, and then stepping off onto the Sun Deck of the AirShip below. Or vice versa, exiting the Sun Deck of one AirShip, by stepping aboard the Spiral Staircase of an AirShip above.

The entire surface of the exterior of the AirShip top, other than the sun deck, will be covered in high density, high efficiency photovoltaics made from the cheapest materials possible.

Construction:

In order to rapidly deploy a global uncensorable and inexpensive network completely supplanting government and corporate controlled networks (current internet), we will need to rapidly expand the human capacity to construct additional AirShip nodes.

The best way to ensure logarithmic growth of the network is to devise a system that is capable of self-replication and rapid iterative design improvements.

3d printing and open source are the cornerstone of rapidly advancing all human technological capability as quickly and safely as possible. But the current generation of 3d printers are not actively capable of self-replication. Too many moving parts, too many stationary design choices, and a lack of mobility all limit the current 3d printing industry.

By having an AirShip 3d printer, one that can carry filament, and also move the active hot end accurately and safely in space to any location, construction of any physical object (including more AirShip 3d Printing Nodes) is possible at a lower cost, with less moving parts, and also more inexpensively.

In addition to rapidly lowering the cost and complexity of 3d printing by having an actively movable and controllable hot end with sub millimeter accuracy, multiple AirShip 3d Printer Nodes can 3d print multiple materials, simultaneously, creating meta-materials vastly superior to any single homogeneous material. For example one AirShip 3d printer can be printing in a sustainable and edible non-toxic hemp based plastic, while another AirShip 3d printer can be printing segments of graphene in the same structure. This can make the graphene an electrical grid, or merely part of the structure in a way that is structural. Not only that, but SEVERAL different materials can be printing on a single structure at the same time, millimeter by millimeter, and at unlimited scale.

In this way, the smaller initial AirShip 3d printers can easily begin constructing larger AirShips collaboratively, and iteratively.

All materials used for this endeavor should be completely reusable, and recyclable. So that outdated AirShip designs can be immediately melted down, and re-purposed for new AirShips or other construction.

### Additional Infrastructure, and Specialized AirShips

The teams constructing AirShips will need to be fed and have access to fresh water while they are building the initial wave of AirShip 3d Printer swarms.

By creating AirShips with the FarmBot style tool heads, we can have a swarm of dedicated specialist AirShips that are actively creating an entire ecosystem food forest based on permaculture principles.

In this way, we will be able to create a radical abundance of organic heirloom food, not just for the initial AirShip production and design team, but for the entire global populace.

This will also be the way in which we can farm and harvest industrial hemp on a vast scale, for more hemp-based plastic filament, HempCrete, Hemp AirCrete, and Hemp based textiles.

Eventually we can build large hydroponic hemp farms that float on the ocean and harvest and desalinate all the water they need directly from the ocean and photovoltaic solar arrays. Leading to an infinite abundance of building and construction materials, not just for more AirShip 3d Printer Nodes and AirShip housing, but for literally any conceivable human construction and design need.

### The Intent

The intent of this project is not to abide by FCC or FAA or IRS rules. The intent is to radically decentralize all human systems and society, giving individuals and families the ultimate freedom from all current control paradigms. By allowing free travel globally, including over international waters and international airspace, we are eliminating government control, taxation, conscription, and law enforcement. By helping to ensure infinite production of food, water, electricity, hydrogen, and construction materials, we are freeing all individuals and families from a life of labor for large corporations or other exploitative businesses and governments. By providing a high bandwidth long range blockchain encrypted network that is untrackable, uncensorable, and unstoppable, we are providing true freedom of speech, freedom of information, and rapid technological development to every person on the planet, without extorting from more fortunate groups through taxation and other forms of violence.

The Intent is total liberty. For all humanity. The Intent is a complete and utter paradigm shift away from all previous systems of governance, finance and lifestyle.

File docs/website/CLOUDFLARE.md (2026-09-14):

# Cloudflare Pages handoff

The production-ready static site lives in `web/`.

## Git integration

Create a Cloudflare Pages project connected to `crhy/OpenAirShips` with:

- Production branch: `main`
- Framework preset: None
- Build command: leave blank
- Build output directory: `web`

Cloudflare will publish a `*.pages.dev` preview before any DNS is moved. Once it is approved, add `openairships.com` and `www.openairships.com` as custom domains in Pages, then follow Cloudflare's displayed DNS changes.

## Local preview

Run `npm install`, then `npm run dev`. A plain static server pointed at `web/` also works.

## Before DNS cutover

- Confirm Discord, GitHub, donation and model links.
- Decide explicit licenses for code, hardware, documentation and media.
- Add current owners/contact destinations for each workstream.
- Review safety and historical claims with qualified sources.
- Replace any concept imagery whose reuse rights are unclear.

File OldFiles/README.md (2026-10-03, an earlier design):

# Old files

Earlier OpenAirShips models, kept for history and reference. They are **not** the current design. For that, see [`CurrentModel/`](../CurrentModel) and its [changelog](../CurrentModel/CHANGELOG.md).

- `CAD/`: FreeCAD models of earlier pie slices.
  - `airship pie slice 125.FCStd` is the direct ancestor of the 926 bench model.
  - The 2-byte 1024 files are empty placeholders; the real model is behind the Google link.
- `PrintFiles/`: earlier printable STLs.
  - `PieSlice1224.stl`
  - the 926 development revisions A–D. **RevB and revC have a duct leak; don't print them.**
- The top-level files are older pie-slice, component and obelisk experiments, logos and prototype photos.
- `PrintFiles/926/` and `CAD/926/`: the released 926 model (v0.1.3 bench and Kobra Max slices, v0.2 double-Kobra pieces), replaced in October 2026 by the 1026 model (flush fan housing, lighter keel).

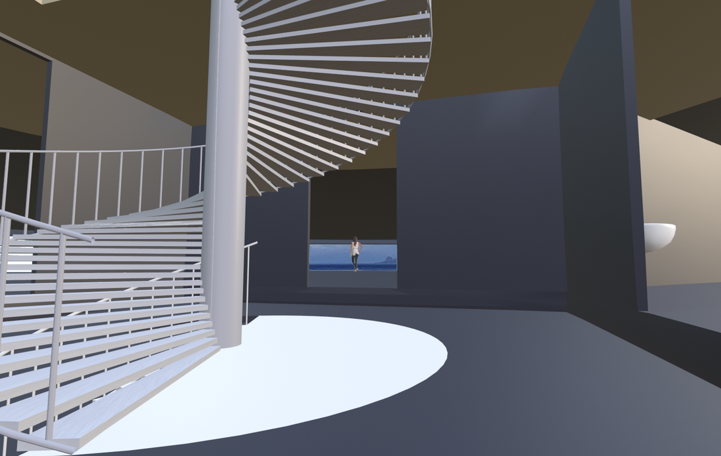
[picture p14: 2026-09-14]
web/assets/images/central-stair-concept.png

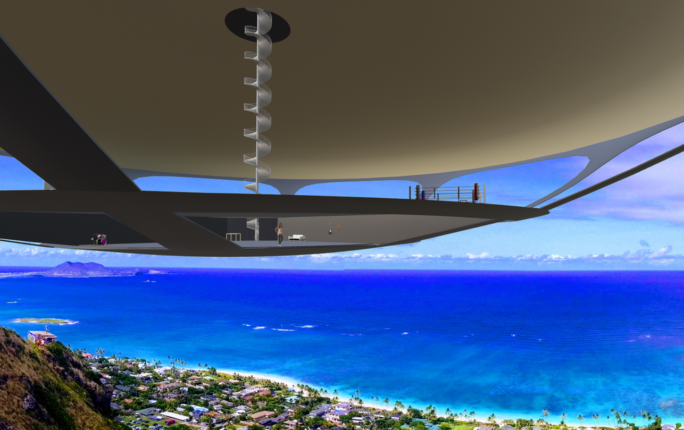
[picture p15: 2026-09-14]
web/assets/images/studio-concept.png

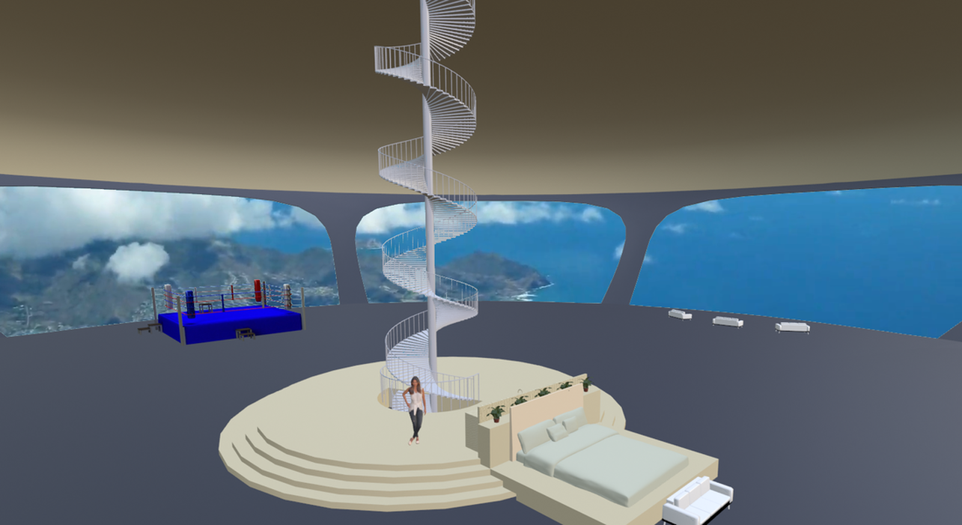
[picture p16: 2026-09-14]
web/assets/images/main-floor-concept.png

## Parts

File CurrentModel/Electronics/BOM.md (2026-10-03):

# Bill of materials: 1026 model (tethered bench demo and self-contained build)

The links are **Amazon search links**, not specific listings. Listings and prices change constantly, so pick a well-reviewed seller. Prices are rough USD estimates as of September 2026. **Check each listing's specs against the "Must match" column before buying.** Those dimensions are the ones the printed parts are designed around.

## Propulsion and control

| # | Part | Qty | Must match | ~USD | Link |
|---|---|---|---|---|---|
| 1 | **2207 1750 KV** brushless motor (5" FPV racing size, 4S rated). The airflow analysis needs about 15,700 rpm; see `../Analysis/AIRFLOW.md` | 1 (+1 spare) | ≈28 mm bell, ≤ 20 mm mount face to bell top, M3 holes on a **16 × 16 mm** square, M5 threaded shaft with a nut, ≈30–35 g | 15–25 each | [search](https://www.amazon.com/s?k=2207+1750KV+brushless+motor+4S) |
| 1a | 45 A BLHeli_S (or BLHeli_32) single ESC, 2–6S | 1 | Standard PWM input (1000–2000 µs); a BEC is optional | 15–25 | [search](https://www.amazon.com/s?k=45A+BLHeli+ESC+2-6S+single) |
| 2 | MG90S metal-gear micro servo | 8 (+2 spare); **4** for the 4-thruster design | 22.8 × 12.2 mm body, 27.8 mm screw pitch, 180° travel | 25–30 for 10 | [search](https://www.amazon.com/s?k=MG90S+metal+gear+micro+servo+10+pack) |
| 3 | ESP32-WROOM-32 DevKitC (38-pin) | 1 (+spare) | Classic ESP32 with Wi-Fi | 15–20 for 3 | [search](https://www.amazon.com/s?k=ESP32+WROOM-32+DevKitC+38+pin) |
| 4 | PCA9685 16-channel 12-bit PWM / servo driver | 1 | Address 0x40; has a V+ screw terminal | 8–12 for 2 | [search](https://www.amazon.com/s?k=PCA9685+16+channel+servo+driver) |
| 5 | 5 V 5 A UBEC (switch-mode regulator for the servo rail) | 1 | 7–25 V in, 5 A continuous | 8–12 | [search](https://www.amazon.com/s?k=5V+5A+UBEC) |

## Power and tether

| # | Part | Qty | Must match | ~USD | Link |
|---|---|---|---|---|---|
| 6 | 4S 1500 mAh LiPo (XT60) + a balance charger. Alternative: a 15 V 350 W supply, with the throttle capped at 90 % | 1–2 | 14.8 V, ≥ 75C (the fan draws about 25 A at full throttle) | 30–45 + 25–40 charger | [search](https://www.amazon.com/s?k=4S+1500mAh+LiPo+XT60) |
| 7 | Inline fuse holder + 30 A fuses (ATC blade or MIDI) | 1 | Rated for 12 AWG | 8–12 | [search](https://www.amazon.com/s?k=inline+fuse+holder+12+AWG+30A) |
| 8 | 12 AWG silicone wire, red/black (battery leads, ≤ 30 cm) + 470 µF 35 V low-ESR capacitor | 1 | Flexible silicone jacket | 10–14 | [search](https://www.amazon.com/s?k=12+AWG+silicone+wire+red+black) |
| 9 | XT60 connector pairs | 1 pack | | 7–10 | [search](https://www.amazon.com/s?k=XT60+connectors+male+female) |
| 10 | Servo extension leads, 30 cm | 10 | JR/Futaba 3-pin | 7–10 | [search](https://www.amazon.com/s?k=servo+extension+cable+30cm+10+pack) |
| 11 | Dupont jumper wires (F-F) | 1 pack | | 6–8 | [search](https://www.amazon.com/s?k=dupont+jumper+wires+female+female) |

## Hardware and consumables

| # | Part | Qty | Must match | ~USD | Link |
|---|---|---|---|---|---|
| 12 | M3 socket-head screw assortment | 1 | Motor to the fan hatch: 4 × M3 × 6 (check your motor's thread depth) | 10–14 | [search](https://www.amazon.com/s?k=M3+socket+head+screw+assortment) |
| 13 | PLA filament, 1.75 mm, 1 kg | 1 | Bench size, 8 thrusters: hull ≈ 300 g (8 × ≈ 38 g), propulsion except the impeller ≈ 290 g. 4 thrusters: hull ≈ 265 g, propulsion ≈ 200 g | 18–22 | [search](https://www.amazon.com/s?k=PLA+filament+1.75mm+1kg) |
| 13b | **Option: lightweight (foaming) PLA**, 1.75 mm, for the hull slices, thruster rings and servo mounts. For example colorFabb LW-PLA or Polymaker PolyLite LW-PLA (check what's sold now) | 1 × 750 g–1 kg (bench size), 1–2 (Kobra Max size) | Density 0.80 g/cm³ with moderate foam, down to about 0.6 at full foam. Airtight walls need moderate foam. Settings: [slice README](../CAD%20Files/SimplifiedSlice/README.md#lightweight-foaming-pla). Weights: [Analysis/FLOAT.md](../Analysis/FLOAT.md) | 35–55 | [search](https://www.amazon.com/s?k=lightweight+PLA+LW-PLA+foaming+filament) |
| 13a | PETG filament, 1.75 mm (the impeller: its tip runs at 72 m/s, and PLA creeps when warm) | 1 small spool | ≈ 8 g per impeller; print 2 | 18–22 | [search](https://www.amazon.com/s?k=PETG+filament+1.75mm) |
| 14 | 5-minute epoxy (airtight seams: shaft, housing, keel, ducts; servo mounts) | 1 | | 7–10 | [search](https://www.amazon.com/s?k=5+minute+epoxy) |
| 15 | CA glue, thin + gel | 1 | | 7–10 | [search](https://www.amazon.com/s?k=CA+glue+thin+gel) |
| 16 | PTFE thread-seal tape (swivel bearing wrap) | 1 | | 3–5 | [search](https://www.amazon.com/s?k=PTFE+tape) |

## Optional, for measurements and later work

| # | Part | Qty | Why | ~USD | Link |
|---|---|---|---|---|---|
| 17 | MPXV7002DP differential pressure sensor | 1 | Plenum pressure versus fan throttle | 12–18 | [search](https://www.amazon.com/s?k=MPXV7002DP) |
| 18 | INA219 or INA226 current/power sensor | 1 | Fan power draw | 6–10 | [search](https://www.amazon.com/s?k=INA226+current+sensor) |
| 19 | BNO085 or MPU6050 IMU | 1 | Heading hold, first flight-control code | 8–25 | [search](https://www.amazon.com/s?k=BNO085+IMU) |
| 20 | Digital kitchen scale, 0.1 g (on the bench as a thrust stand) | 1 | Measuring lift and thrust | 10–15 | [search](https://www.amazon.com/s?k=digital+scale+0.1g) |
| 21 | Spare 4S 1500 mAh LiPo | 1 | Longer bench sessions | 30–45 | [search](https://www.amazon.com/s?k=4S+1500mAh+LiPo+XT60) |

**Core cost (items 1–16):** about $230–320. The optional items add about $40–140.

## v0.2 self-contained double-Kobra build: changes to the list above

This build carries its own battery and controller (no tether). Its airborne-weight budget is in [../Analysis/FLOAT.md](../Analysis/FLOAT.md). Use the list above with these changes:

| # | Part | Qty | Must match | ~USD | Link |
|---|---|---|---|---|---|
| S1 | **SG90 micro servo** (instead of MG90S): 9 g against 13.4 g. The rings need little torque | 4 (+2 spare) | Same 22.8 × 12.2 mm body and 27.8 mm screw pitch as the MG90S, so the servo mounts fit | 10–15 for 6 | [search](https://www.amazon.com/s?k=SG90+micro+servo) |
| S2 | **30 A ESC** (instead of 45 A): ~7 g. The fan peaks at ~25 A | 1 | 2–4S, standard PWM input | 12–18 | [search](https://www.amazon.com/s?k=30A+BLHeli+ESC+2-4S) |
| S3 | **2S 18650 Li-ion pack** (2 cells side by side, with leads). Two in series make 4S 2.8 Ah (41 Wh, ~195 g). One sits in each tray cradle, so the ship stays balanced | 2 | High-drain cells (Molicel P28A or similar, ≥ 25 A), about 40 × 70 × 20 mm | 20–35 each | [search](https://www.amazon.com/s?k=2S+18650+battery+pack+Molicel+P28A) |
| S4 | 3 A BEC, 5 V (instead of the 5 A UBEC): ~6 g | 1 | 2–6S in | 6–10 | [search](https://www.amazon.com/s?k=3A+BEC+5V+mini) |
| S5 | IMU + barometer board (e.g. GY-91: MPU9250 + BMP280): ~4 g | 1 | I²C | 8–15 | [search](https://www.amazon.com/s?k=GY-91+MPU9250+BMP280) |
| S6 | 100 kΩ and 22 kΩ resistors (battery-voltage divider to GPIO 34) | 1 each | | 5 (kit) | [search](https://www.amazon.com/s?k=resistor+kit+1%2F4W) |
| S7 | Small latching power switch, 30 A, or an XT30 loop-key | 1 | Outside the gas cells | 5–10 | [search](https://www.amazon.com/s?k=XT30+connectors) |
| S8 | Lightweight PLA (full foam) for the hull pieces, tubes, rings, mounts and tray | 1–2 kg | See the slice README's lightweight-PLA settings | 35–55 per kg | [search](https://www.amazon.com/s?k=lightweight+PLA+LW-PLA+foaming+filament) |
| S9 | 12 µm LDPE film (gas cells) and a heat sealer | ~7 m² | | 15–30 | [search](https://www.amazon.com/s?k=LDPE+film+roll+thin) |

- **Not needed:** the PCA9685 board (item 4). The ESP32 drives the 4 servos and the ESC directly; see the firmware notes.
- **Also not needed:** the bench power supply, fuse and tether wire (items 6–8).

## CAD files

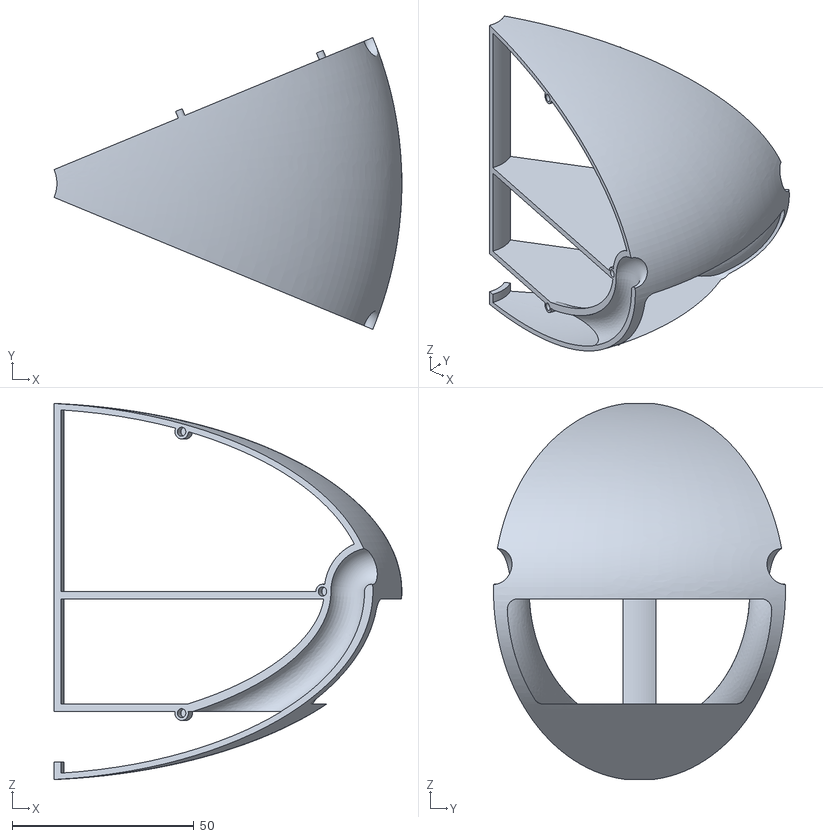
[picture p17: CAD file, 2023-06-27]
airship_pie-slice_obelisk.stl
95.8 x 80.4 x 103.5

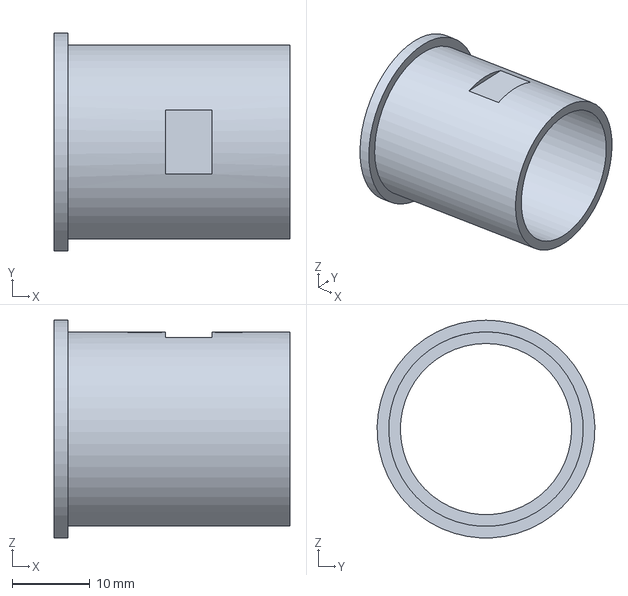
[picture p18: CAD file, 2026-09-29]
CurrentModel/CAD Files/Propulsion/4T/small/12s/x3.8/stem.step
30.3 x 28.0 x 28.0 mm

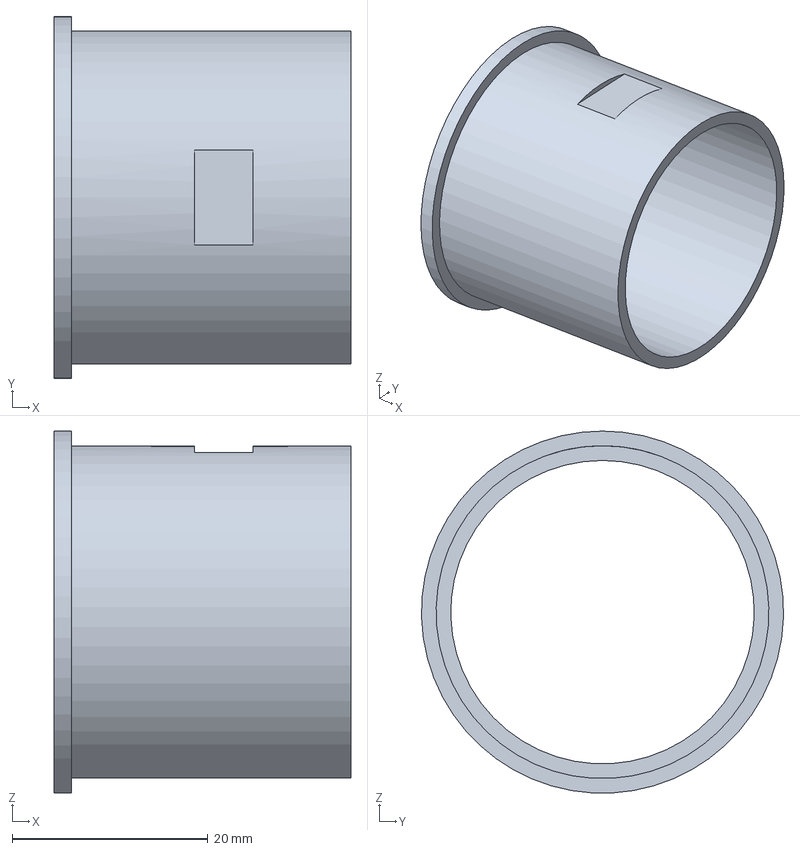
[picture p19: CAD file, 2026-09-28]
CurrentModel/CAD Files/Propulsion/4T/stem.step
30.3 x 37.0 x 37.0 mm

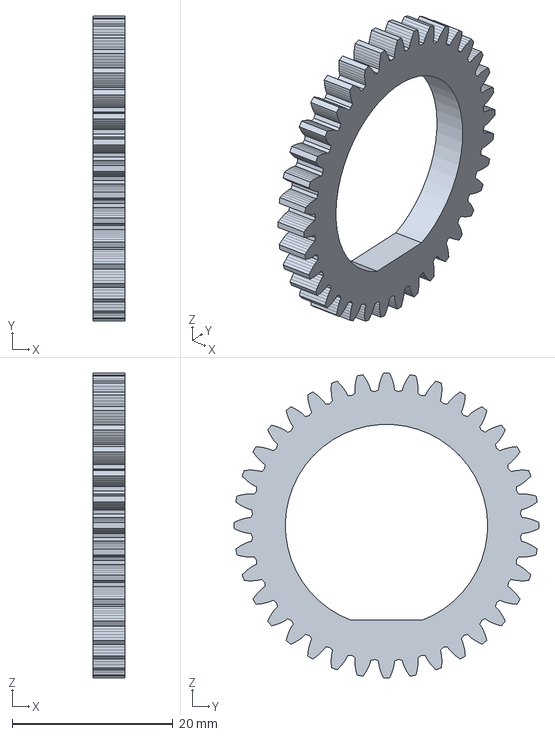
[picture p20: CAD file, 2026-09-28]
CurrentModel/CAD Files/Propulsion/stem_gear.step
4.00 x 38.0 x 38.0 mm

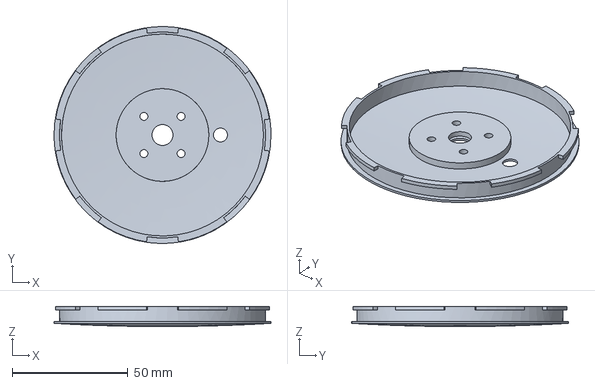
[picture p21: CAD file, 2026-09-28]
CurrentModel/CAD Files/Propulsion/x1.9/fan_hatch.step
93.6 x 93.6 x 8.69 mm

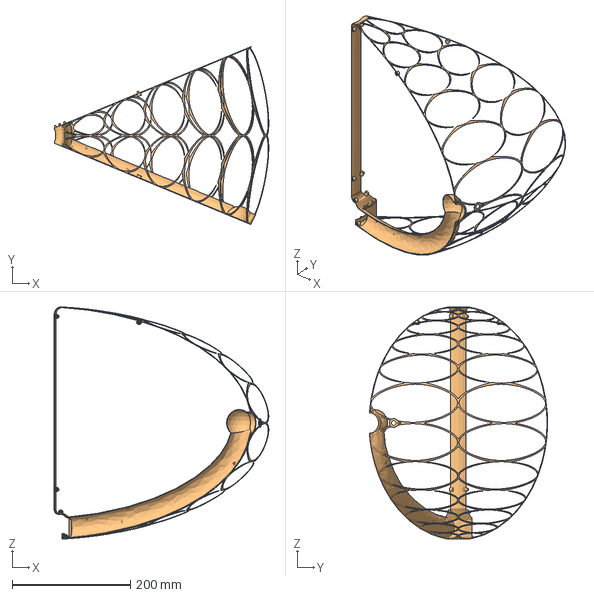
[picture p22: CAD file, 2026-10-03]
CurrentModel/CAD Files/SimplifiedSlice/airship pie slice 1026 4T right x1.9.FCStd
363.1 x 301.5 x 392.5 mm
SimplifiedSlice

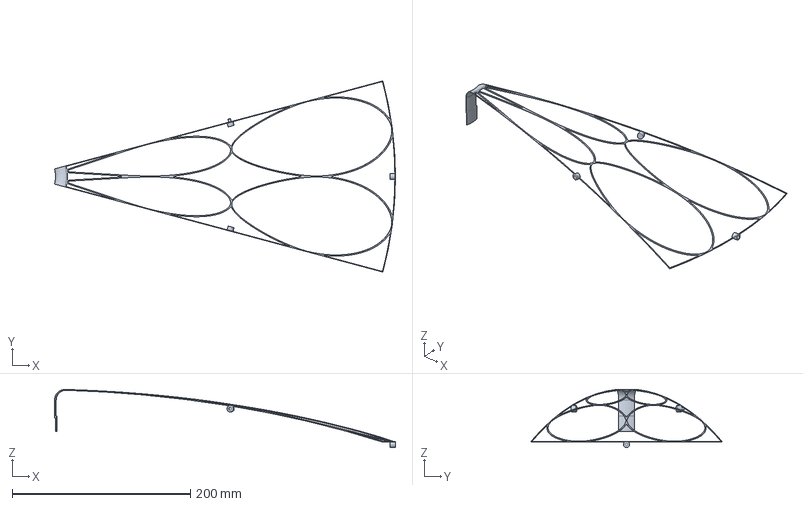
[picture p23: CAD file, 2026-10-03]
CurrentModel/CAD Files/SimplifiedSlice/pieces/airship pie slice 1026 4T left 12s small x3.8/top_inner.step
383.1 x 214.8 x 65.2 mm

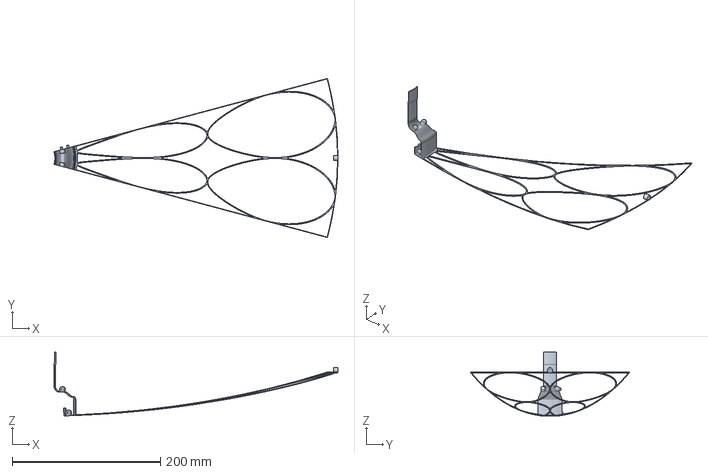
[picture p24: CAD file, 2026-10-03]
CurrentModel/CAD Files/SimplifiedSlice/pieces/airship pie slice 1026 4T plain 12s small x3.8/bottom_inner.step
383.1 x 214.8 x 86.0 mm

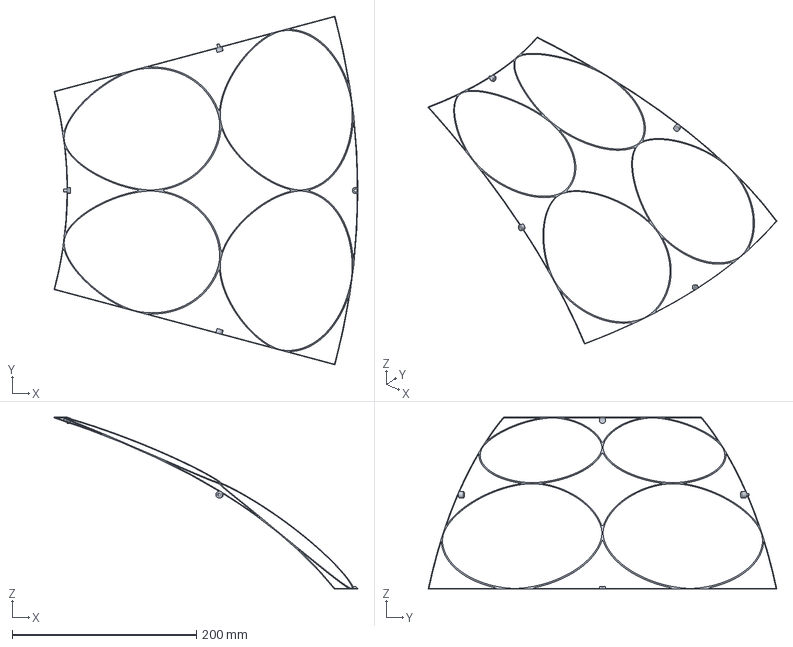
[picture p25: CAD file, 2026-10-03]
CurrentModel/CAD Files/SimplifiedSlice/pieces/airship pie slice 1026 4T right 12s small x3.8/top_outer.step
329.6 x 378.1 x 186.2 mm

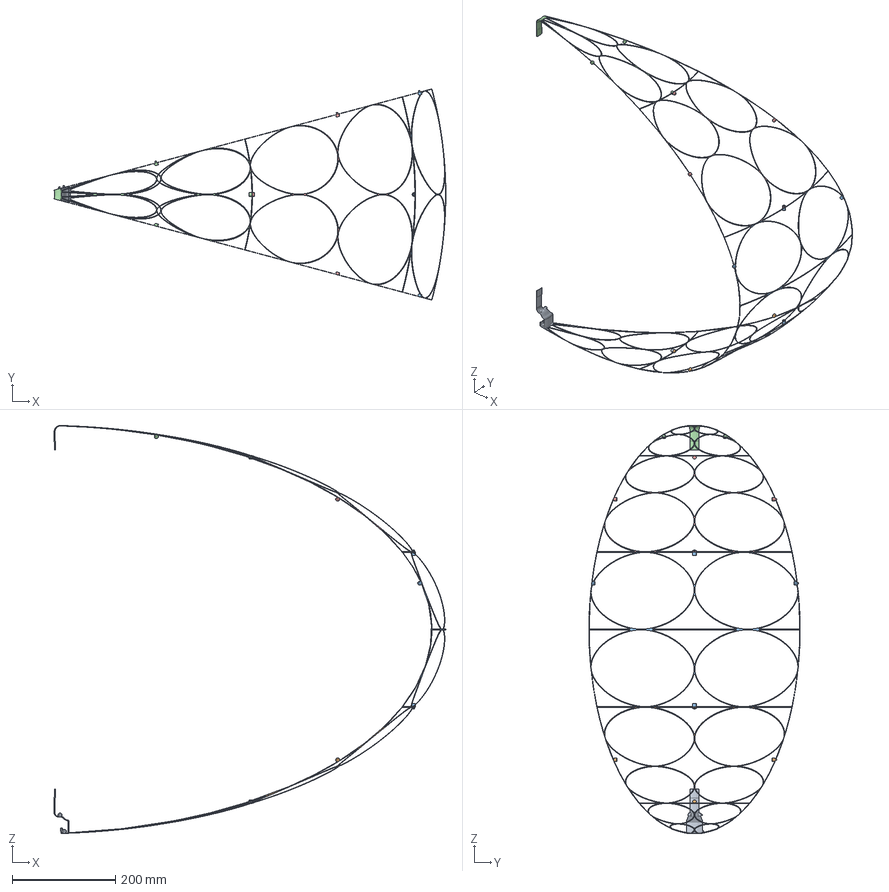
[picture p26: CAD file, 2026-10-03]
CurrentModel/CAD Files/SimplifiedSlice/pieces/airship pie slice 1026 v0.2.1 plain (pieces).FCStd
757.6 x 408.6 x 789.0 mm
bottom_inner
bottom_outer
middle
top_inner
top_outer

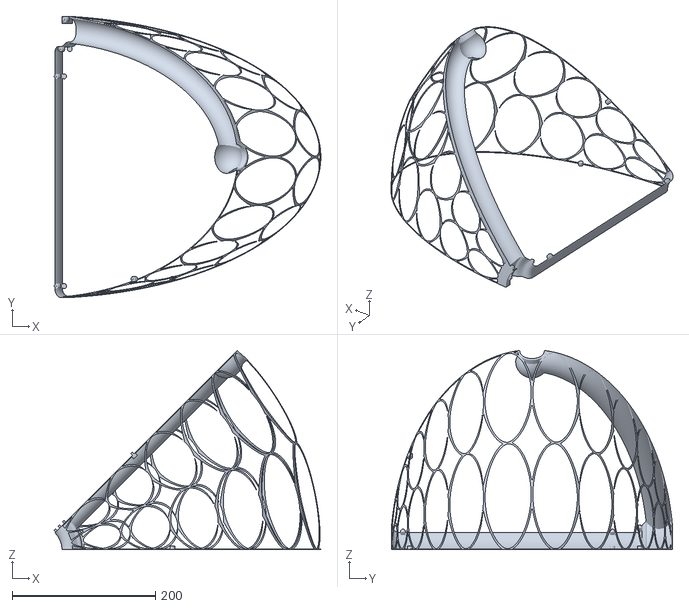
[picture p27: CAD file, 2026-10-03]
CurrentModel/Print Files/PieSlice1026-v0.2.1-4T-left-KobraMax.stl
372.5 x 392.5 x 278.1

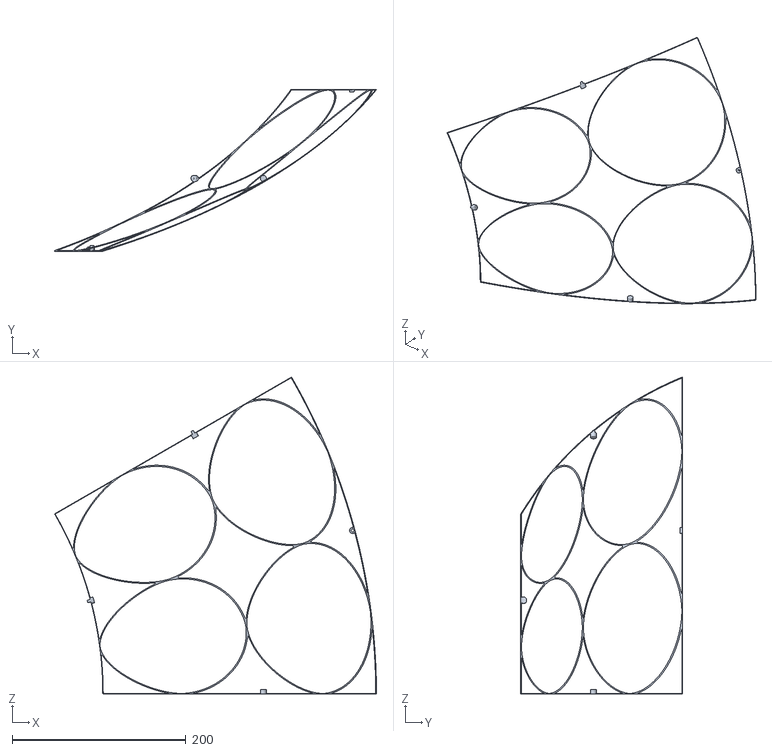
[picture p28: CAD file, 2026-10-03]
CurrentModel/Print Files/v0.2.1 double Kobra/PieSlice1026-v0.2.1-left-top-outer.stl
371.0 x 186.2 x 365.2

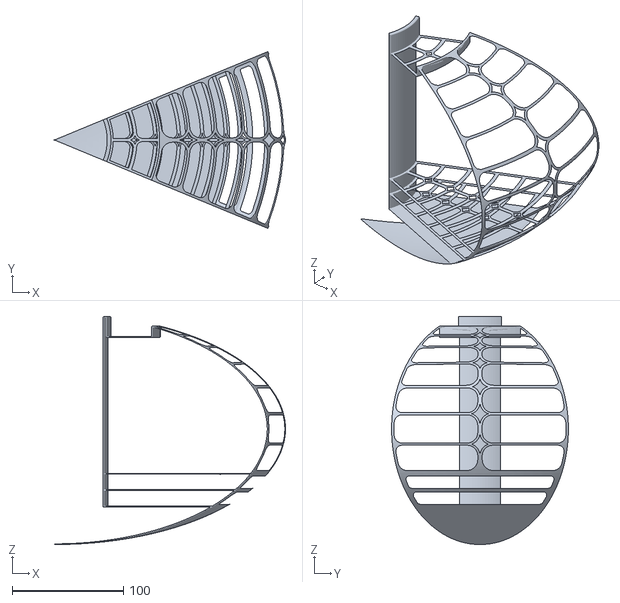
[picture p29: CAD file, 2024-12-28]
web/assets/models/openairship-wedge.stl
207.8 x 159.0 x 205.2

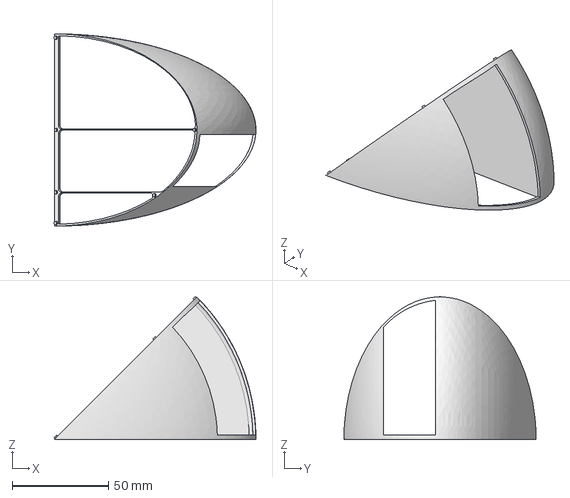
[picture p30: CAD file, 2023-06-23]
AirShipComponentC623.FCStd
105.2 x 100.1 x 74.5 mm

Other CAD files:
CurrentModel/airship_pie-slice_924c.FCStd
CurrentModel/CAD Files/Propulsion/4T/x1.9/stem.step
CurrentModel/CAD Files/Propulsion/4T/impeller.step
CurrentModel/CAD Files/Propulsion/4T/small/12s/x3.8/servo_gear.step
AirShipComponentC.FCStd
CurrentModel/CAD Files/Propulsion/4T/fan_hatch.step
CurrentModel/CAD Files/Propulsion/4T/print/fan_hatch.stl
CurrentModel/CAD Files/Propulsion/4T/print/servo_gear.stl
CurrentModel/CAD Files/Propulsion/4T/print/servo_mount.stl
CurrentModel/CAD Files/Propulsion/4T/print/stem.stl
CurrentModel/CAD Files/Propulsion/4T/print/stem_gear.stl
CurrentModel/CAD Files/Propulsion/4T/print/thruster_ring.stl
CurrentModel/CAD Files/Propulsion/4T/propulsion 1026 4T.FCStd
CurrentModel/CAD Files/Propulsion/4T/servo_gear.step
CurrentModel/CAD Files/Propulsion/4T/servo_mount.step
CurrentModel/CAD Files/Propulsion/4T/small/12s/x3.8/avionics_tray.step
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

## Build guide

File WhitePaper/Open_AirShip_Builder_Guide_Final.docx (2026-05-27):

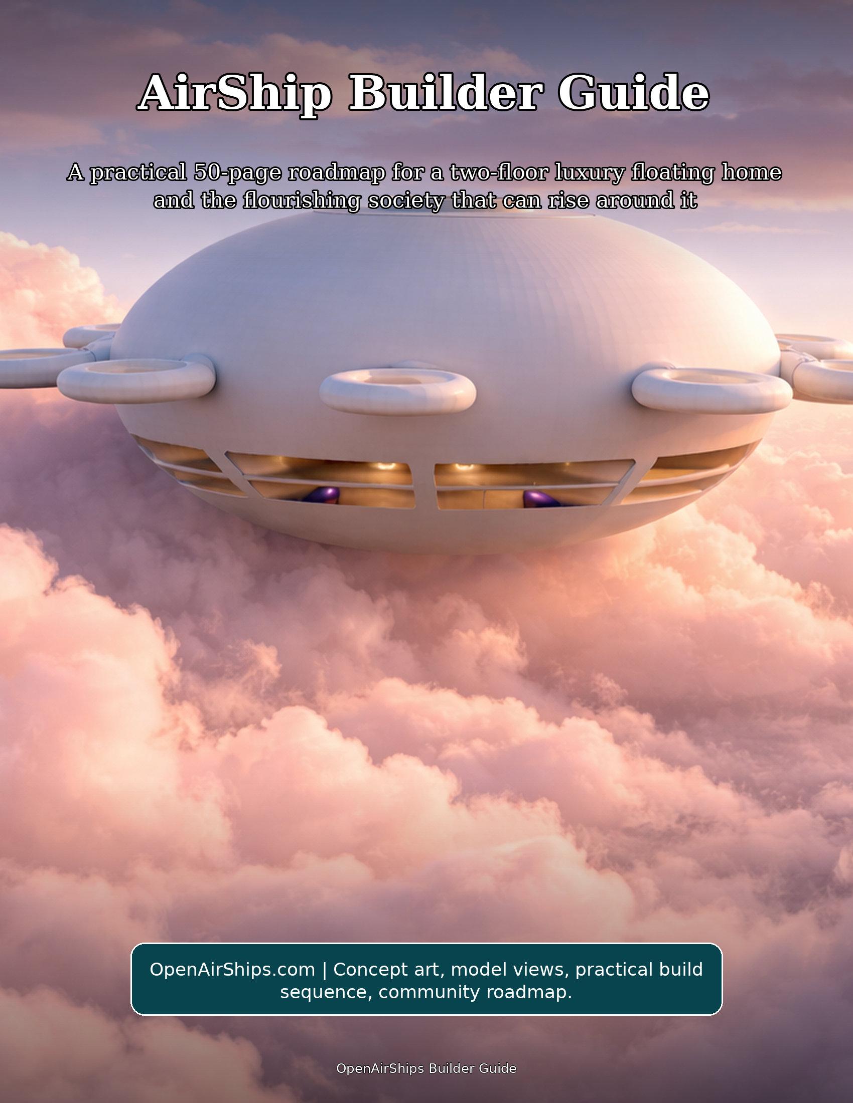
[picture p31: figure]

# How to Read This Guide

This guide is written for a future AirShip builder who wants a practical path from vision to working prototype. The craft is treated as a round, low-profile, modular, two-floor luxury floating home, with its broad circular hull, upper sun-deck opening, eight perimeter assemblies, and visible two-floor interior band serving as the central design reference.

The pages are arranged as a builder journey. First, they define the spirit and geometry. Then they move into team formation, digital modeling, material research, interior planning, lift architecture, solar power, controls, community economics, food systems, and the flourishing society that can grow around a fleet of beautiful homes in the sky.

The guide stays practical by design. It focuses on constructive action, clear roles, prototyping discipline, open documentation, shared abundance, and graceful iteration. Whenever the work requires deep specialization, the practical step is to invite the right expert into the build circle and make their contribution part of the open design commons.

## Workshop actions

• Print the reference-geometry pages and keep them in the workshop.

• Name a documentation steward responsible for keeping the reference atlas current.

• Create a shared build journal before any CAD changes are proposed.

# The Promise of the AirShip Home

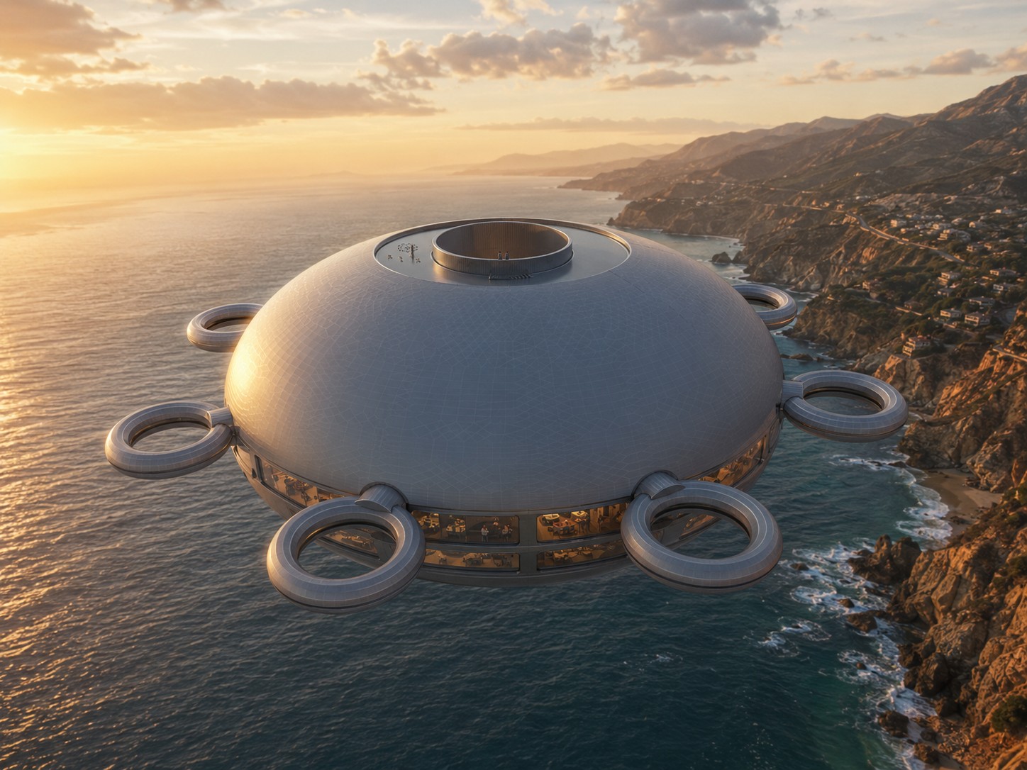
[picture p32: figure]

Hero concept view: the reference AirShip presented as a two-floor floating home.

“Build the home as if every curve is an invitation: to travel lightly, live beautifully, and help others rise with you.”

An AirShip home is more than a vehicle. It is a calm, solar-facing dwelling that carries household life into three-dimensional space. The supplied model already expresses a distinct promise: a broad circular hull, eight symmetrical docking and propulsion points, an upper sun-deck opening, and a visible two-floor interior band in the x-axis view.

The practical ambition is a floating home that feels luxurious because it is spacious, quiet, resource-aware, and community-connected. Luxury here does not mean excess. It means good light, generous air, open views, elegant circulation, durable materials, resilient power, and rooms designed for rest, study, cooking, growing, and gathering.

The social ambition is equally important. The AirShip becomes a node in a new culture of mobility and mutual aid: homes that can gather, separate, exchange resources, host guests, teach skills, grow food, print components, and share knowledge across a living network.

# Reference Geometry and Modular Identity

The supplied model defines the project's reference geometry. The round plan, smooth dome, low vertical profile, two-floor side band, and eight perimeter assemblies form the visual and functional identity of the AirShip.

Design work begins with the existing envelope. Engineering, interiors, systems, service spaces, and finish details can be developed as coordinated layers inside a recognizable platform that can be studied, tested, fabricated, repaired, and celebrated as a coherent family of craft.

A shared reference model makes collaboration easier. Every contributor can work from a common origin, common axes, common modular wedge logic, and common reference views. This keeps design conversations focused on refinement, documentation, and elegant execution.

## Foundation tasks

• Freeze the master hull mesh in a read-only archive.

• Create derivative layers only for internal systems, panels, furniture, utilities, and documentation.

• Use revision names that distinguish production work from exploratory sketches.

# Reading the Supplied Views

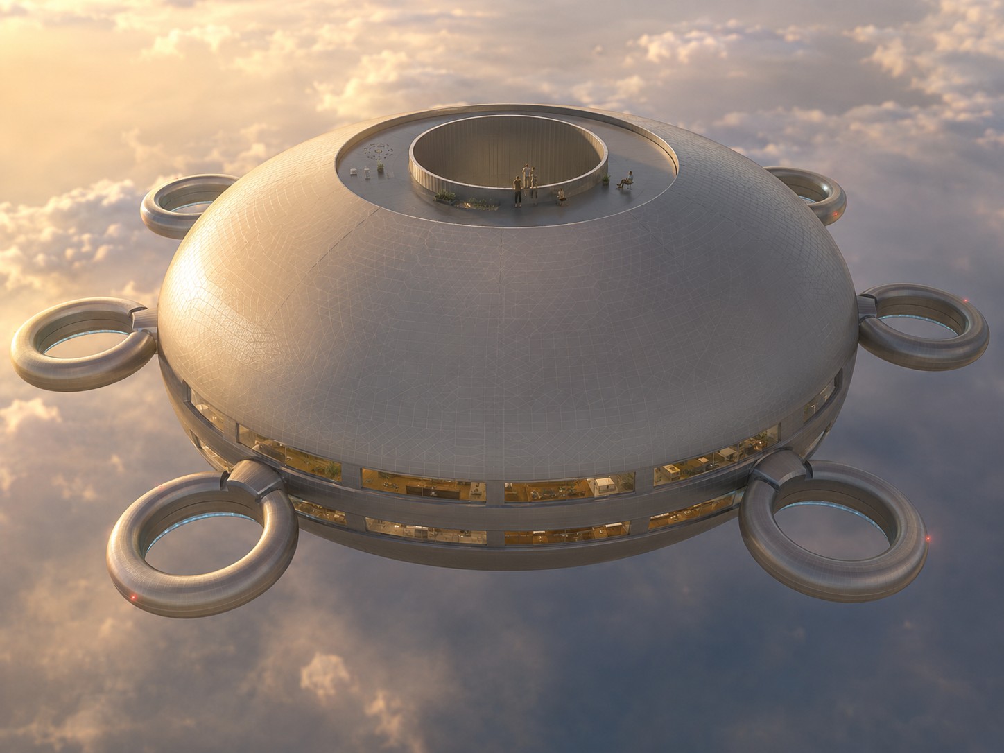
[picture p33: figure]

Reference view: central access ring, smooth upper hull, and perimeter modules.

The perspective view shows the craft as a smooth, broad, rounded body with a recessed upper zone and a central cylindrical access opening. The top views reveal radial symmetry and the ring modules around the circumference. The side view reveals the crucial two-floor band: upper living volume above, lower service and living volume below, with windows or bays distributed across the horizontal axis.

A builder should translate these views into a design atlas. Each view becomes a control drawing: top plan for module spacing, side view for floor separation, perspective view for character, and underside or alternate top view for access and maintenance interpretation. This atlas can be used in every design review.

The most practical first step is not cutting material. It is naming every visible feature. Once the features have names, builders can assign owners, create checklists, and develop prototypes without arguing about what the geometry means.

## Geometry tasks

• Label the eight perimeter modules clockwise as P1 through P8.

• Label the upper access ring, recessed solar field, outer hull shell, two floor band, lower service zone, and interior stair core.

• Create a one-page visual glossary and include it in every build packet.

# OpenAirShips Design Lineage

The OpenAirShips source documents describe a modular, open-source AirShip vision built around circular sections, low-cost iteration, solar power, 3D printing, mesh networking, and a society of mutual provision. The public OpenAirShips.com overview also frames the project around small modular open-source autonomous AirShips that can scale toward travel, housing, electricity, internet, clean water, and abundance.

The important builder lesson is that the AirShip is a platform, not a single product. A platform can host homes, workshops, gardens, sensors, routers, classrooms, guest spaces, water systems, and creative studios. That is why modularity matters: the same outer form can support many interior missions.

The practical path is to honor the source idea while making it buildable. Translate the vision into staged prototypes, documented subsystems, community review, and repeatable fabrication recipes that align with the reference geometry.

## View-study tasks

• Create a source folder with the white paper, transcripts, screenshots, public site snapshots, and model files.

• Separate vision statements from engineering requirements so both can thrive.

• Turn each recurring idea into a build track: hull, lift, power, interior, controls, network, society.

# The Builder Mindset

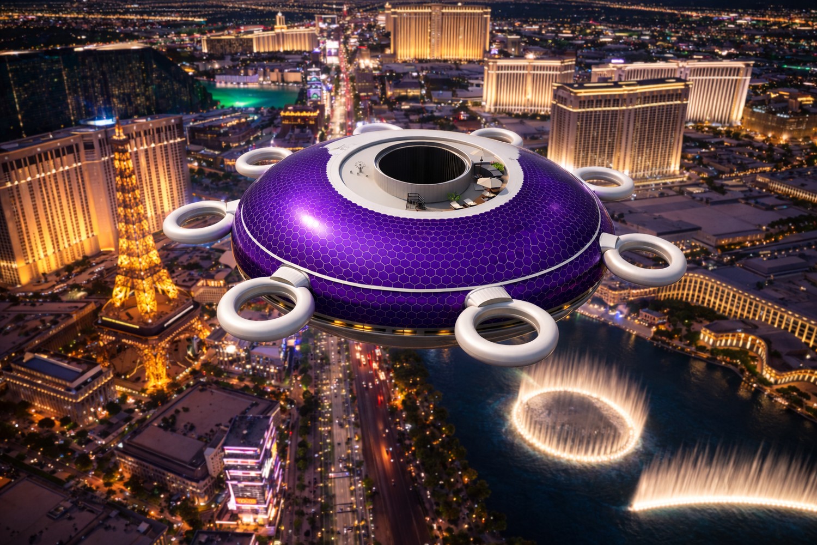
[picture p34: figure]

Concept lineage: OpenAirShips ideas translated into a practical build language.

A potential AirShip builder needs three virtues: patience with iteration, generosity with knowledge, and devotion to elegant execution. The work becomes joyful when each prototype is treated as a contribution to the shared future rather than a private secret.

The best builder mindset is both artistic and empirical. The model has a poetic presence, but the path to flight, comfort, and long service life is a careful sequence of drawings, simulations, small models, subsystem benches, full-scale mockups, and community reviews. Every stage should produce something useful: a diagram, a test result, a part library, a training note, or a better question.

The builder should also think like a host. This is a luxury floating home. People will sleep, cook, bathe, work, learn, welcome guests, and look out over changing horizons. The craft should make everyday life feel grounded even while it floats.

## Source-library tasks

• Write a one-page builder oath centered on beauty, openness, comfort, and service.

• Choose a weekly design rhythm: review, prototype, document, publish.

• Make every meeting end with one visible improvement to the shared build library.

# Phase 1: Assemble the Circle

Form the first build circle around clear roles rather than vague enthusiasm. The minimum circle includes a project steward, geometry steward, CAD lead, aeronautical advisor, materials advisor, electrical systems lead, interiors lead, controls lead, documentation lead, and community coordinator. Each person owns a track while still contributing to the whole.

In practice, this means treating the AirShip as both artifact and institution. The artifact is the AirShip home; the institution is the open community that keeps improving it. Each page of the build journal should therefore answer two questions: what did we make, and how does it help people live more freely, comfortably, and cooperatively?

A builder who follows this approach will always have a next action. The action may be a drawing, a phone call, a prototype, a meeting, a material sample, a render, a checklist, or a lesson. Small, visible steps create the trust required for a large and inspiring build.

## Builder habits

• Publish role cards.

• Host a model walkthrough.

• Create an open decision log.

# Phase 2: Create the Master CAD Atlas

Workshop image: the builder mindset turns geometry, craft, and documentation into one habit.

The CAD atlas converts screenshots and model files into shared references. It should include top, side, perspective, section, interior, and module views. The key principle is that the exterior hull remains locked while internal structure and systems gain more definition.

Phase 2 technical focus: convert every supplied view into a controlled CAD reference. Use a common origin at the visual center of the craft, align the vertical axis through the central cylinder, and create locked reference planes for top, side, underside, and perspective views. Establish a naming scheme for hull shell, upper access ring, two-floor band, lower service bay, perimeter modules, and internal core so every contributor can attach work to the same coordinate system.

Build the atlas as a package rather than a single file: master mesh, simplified collision model, presentation model, fabrication model, section cuts, and exploded modules. Keep a revision register with author, date, purpose, affected subsystem, and export format. The public OpenAirShips plan calls for repeated global iterative open source revision, so the CAD archive should make comparison, rollback, remixing, and review effortless.

## Circle launch tasks

• Archive original files.

• Define axes and origin.

• Create non-destructive layers.

# Phase 3: Wedge-Based Modularity

The circular body naturally invites radial wedge modules. A wedge can hold structure, buoyancy volume, utilities, cabin zones, storage, or service access while sharing the same geometry with its neighbors. Repetition lowers complexity and makes the AirShip easier to teach, print, inspect, and repair.

Phase 3 technical focus: use the circular plan as a manufacturing advantage. Divide the craft into equal radial sectors, each with shared interface geometry for structure, utilities, buoyancy service, inspection access, and interior fit-out. The white paper emphasizes homogeneous circular sections because one tested wedge can inform the next seven, reducing the number of unique molds, tools, checks, and assembly procedures required for a full hull.

For each wedge, document hard points, wire chases, duct paths, panel seams, fastener families, service covers, and allowable interior attachments. A good module standard includes a drawing, a bill of materials, print orientation notes, joining details, access clearances, and a lightweight inspection checklist. Once the wedge interface is stable, the team can improve individual components without reopening the entire craft design.

## CAD atlas tasks

• Divide the plan into equal sectors.

• Assign module interfaces.

• Prototype one wedge before multiplying it.

# Phase 4: The Two-Floor Luxury Plan

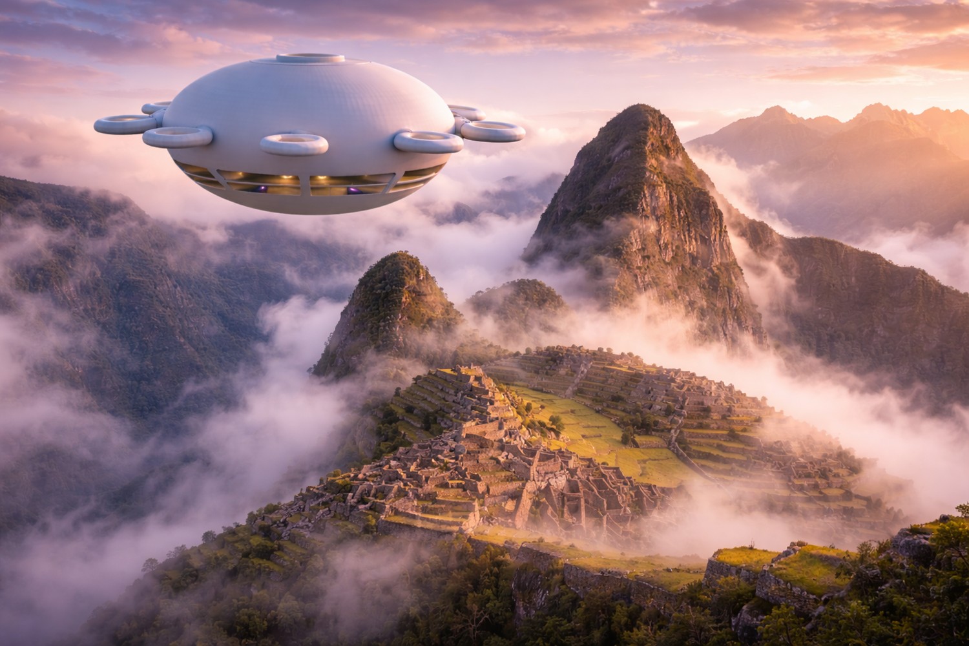
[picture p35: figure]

CAD reference: top, side, and perspective views become the shared atlas.

The side view shows the AirShip as a two-floor floating home. The upper floor can celebrate light, views, cooking, dining, social space, and the sun-deck connection. The lower floor can host private suites, water systems, quiet workrooms, storage, and service corridors.

Phase 4 technical focus: treat the visible side band as the planning datum for two complete living levels. The upper deck can prioritize panoramic social space, galley, dining, work tables, and direct access to the sun-deck core. The lower deck can carry sleeping cabins, quiet rooms, storage, mechanical closets, water systems, sanitation, and service corridors arranged around the same central circulation spine.

Develop the interior as concentric zones. The central core carries stairs, vertical utilities, shared equipment, and the hatch sequence. The middle ring holds daily living functions. The outer ring captures the best views with long windows, built-in seating, cabinets, work surfaces, and balcony-like observation areas inside the fixed shell. Furniture should be modeled as structural mass early so weight distribution stays visible in every drawing.

## Module tasks

• Draw floor plates inside the fixed envelope.

• Reserve a central vertical core.

• Keep windows aligned with the existing side band.

# Phase 5: The Sun Deck as Civic Heart

The top access ring and recessed upper zone suggest a sun deck that is both private terrace and community interface. It can host gathering, solar maintenance paths, plant containers, meditation, stargazing, and graceful arrival from another AirShip.

Phase 5 technical focus: make the upper deck a real operating surface, not decorative space. The model shows a recessed top field and central opening; that geometry can organize solar service walkways, exterior seating, planter pockets, maintenance tie-downs, antenna masts, sensor housings, and weather-rated access panels while preserving the smooth body language of the craft.

Draw the deck in layers: drainage plane, walking surface, solar zones, access ring, hatch detail, handhold locations, lighting, data ports, and service panels. Keep the sun-deck specification practical: replaceable modules, clean cable routes, low-profile fixtures, and durable finishes. The result should feel like a terrace in the sky and function like an orderly roof plant room.

## Interior planning tasks

• Map walking paths.

• Place furniture as removable modules.

• Preserve solar exposure.

# Phase 6: Interior Circulation

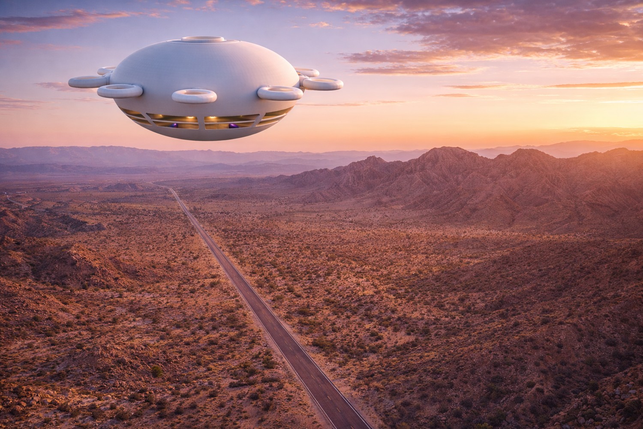
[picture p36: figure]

Interior planning view: the visible side band supports the two-floor home concept.

A luxury floating home needs circulation that feels intuitive. The central vertical core can connect the sun deck, upper floor, lower floor, and bottom access point. Around it, radial corridors can serve rooms without breaking the smooth exterior.

Phase 6 technical focus: the central cylindrical opening becomes the vertical address of the AirShip. Use it to coordinate stair geometry, daylight, ventilation paths, utility risers, emergency egress drawings, equipment access, and the relationship between upper deck, main living floor, lower living floor, and underside service exit. The white paper specifically imagines a spiral stair connecting the sun deck, main interior, and lower exit.

Model circulation at human scale with simple clearances: shoulder width, handrail reach, step rhythm, landing intervals, luggage movement, appliance delivery, and maintenance access. Create a full-size mockup of three stair segments, a hatch ring, and one curved wall section. This single mockup will reveal proportions, hand feel, lighting opportunities, and where the AirShip begins to feel like a home instead of a shell.

## Deck development tasks

• Design a central stair/elevator concept.

• Keep service runs near the core.

• Use curved interior walls to echo the hull.

# Phase 7: Habitability and Comfort

The AirShip should feel serene. Comfort comes from daylight, acoustic softness, stable temperature, fresh air, generous storage, well-placed handholds, and rooms that can shift between travel, rest, and hosting.

Phase 7 technical focus: habitability depends on light, acoustics, temperature control, privacy, storage, and easy maintenance. Assign each cabin and shared room a comfort brief: seating count, sleeping count, expected noise level, daylight target, ventilation path, storage volume, power outlets, data ports, water access, and cleaning method. Luxury becomes measurable when each space is simple to occupy and simple to service.

Use the two-floor band for layered comfort. Put lively functions near shared view areas, quiet functions behind acoustic partitions, service equipment behind accessible panels, and storage where curved geometry would otherwise be wasted. The AirShip should read as advanced technology from outside and as an elegant apartment inside: warm surfaces, clear paths, hidden systems, and windows placed for long, cinematic horizons.

## Circulation tasks

• Create a room-by-room comfort checklist.

• Mock up one cabin at full scale.

• Invite future residents to test layouts.

# Phase 8: Materials Palette

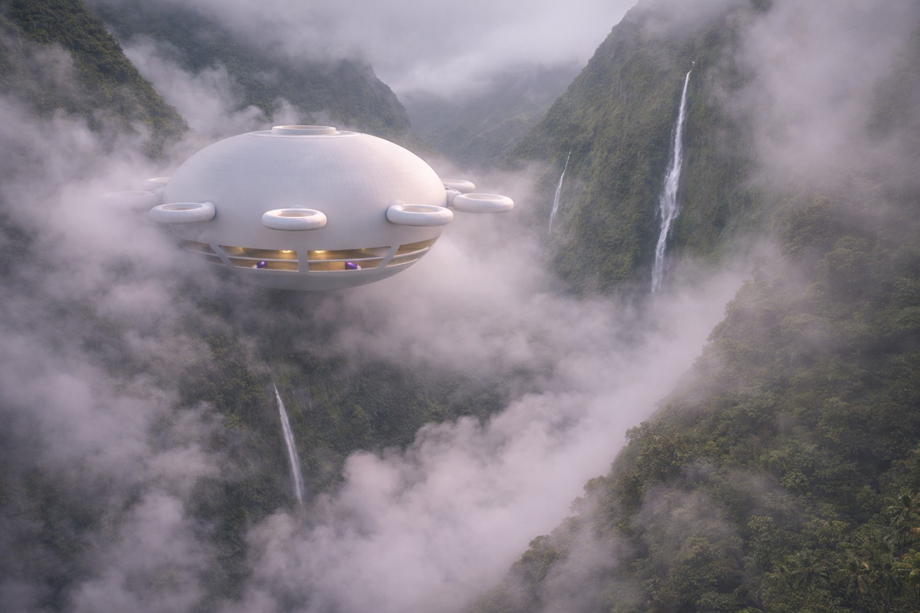
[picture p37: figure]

Circulation study: the central core organizes deck access, stairs, and service routes.

The source vision emphasizes abundant materials, carbon-based structures, 3D printing, recyclability, and solar-facing surfaces. The builder path is to create a material library ranked by strength, weight, repairability, printability, finish quality, and availability.

Phase 8 technical focus: organize materials by job, not by fashion. The source documents discuss carbon for carbon fiber and graphene concepts, nitrogen as an inert buffer, hydrogen produced from water by electrolysis, photovoltaics, hemp-based printable materials, and reusable or recyclable construction stock. Build a matrix with columns for structural role, mass, repairability, recyclability, printability, conductivity, finish quality, and supply chain maturity.

Run material trials as small coupons before committing to assemblies. Each coupon should record weight, stiffness, surface finish, joining method, thermal behavior, fastening behavior, and finish compatibility. For printable components, include nozzle size, layer height, infill, fiber orientation, post-processing, and part marking. The AirShip project improves fastest when every material choice creates data that another builder can repeat.

## Comfort tasks

• Build sample coupons.

• Record mass and finish notes.

• Select materials through transparent review.

# Phase 9: Structural Rings and Frames

The exterior rings visible around the craft can be treated as functional modules: docking collars, propulsion housings, observation rings, service ports, or printable structural subassemblies. Their shared geometry makes them excellent candidates for early fabrication practice.

Phase 9 technical focus: the hull needs a disciplined hierarchy of rings, ribs, frames, panels, and service openings. Begin with major circular rings around the central core and perimeter belt, then connect them with radial frames that align to the wedge modules. This allows windows, cabins, buoyancy cells, utility runs, and exterior panels to reference the same structural grid instead of competing for space.

Produce three structural models: a clean visual model for form review, a simplified engineering model for loads and stiffness, and a fabrication model for joints and subassemblies. Label every frame by sector and elevation. Design joints so panels can be removed for inspection without disturbing finished interiors. The builder's goal is a beautiful shell that also behaves like a well-indexed kit of parts.

## Material trials

• Model one perimeter ring in detail.

• Define its mechanical interface.

• Print display-scale and test-fit versions.

# Phase 10: Lift Architecture

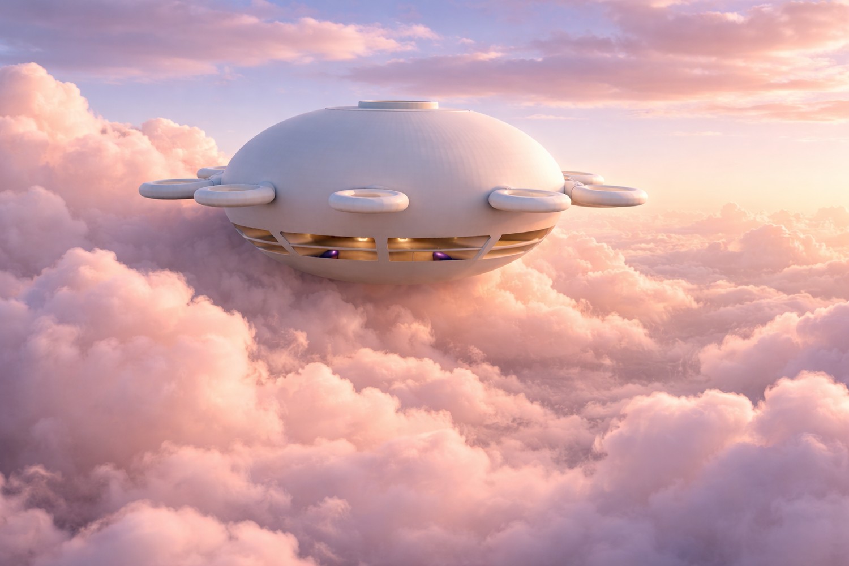
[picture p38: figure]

Materials study: structure, skin, energy, and interiors are chosen as coordinated systems.

At a conceptual level, the AirShip is organized around buoyant volume, compartmentalized lift cells, trim management, and a structural shell that keeps the home form coherent. The builder team should turn this into a professionally modeled lift architecture that fits inside the fixed hull.

Phase 10 technical focus: lift planning begins with the buoyant volume budget. The white paper centers lighter-than-air operation and describes hydrogen as abundant and obtainable from water through electrolysis, with lift managed by gas handling and internal buoyancy architecture. In the guide, treat lift cells, service corridors, sensors, valves, tanks, and access panels as reserved volumes in the CAD model from the first planning pass.

Create a lift ledger that tracks estimated mass by subsystem: shell, frames, windows, interiors, power, storage, propulsion, water, equipment, residents, supplies, and margin. Pair it with a volume ledger for buoyancy spaces. The ledger should be updated after every design change, render, mockup, or part sample so the craft remains a coordinated flying home rather than a collection of attractive rooms.

## Frame development tasks

• Create a volume map.

• Assign lift compartments to wedges.

• Review with aerostatics specialists.

# Phase 11: Solar Skin

The upper exterior is the natural solar field. Solar design should follow the existing curvature and recessed top geometry. The goal is a beautiful integrated skin, not a patchwork. Maintenance paths and replaceable panel zones can be planned as part of the surface system.

Phase 11 technical focus: the upper exterior is the natural solar field. The white paper imagines high-density photovoltaics over the exterior top apart from the sun deck, and the public plan emphasizes scaling with off-the-shelf components. Map solar coverage by curvature, shadow from the central ring, service walkways, module seams, cleaning access, cable routing, inverter placement, and replacement strategy.

Design solar skin as replaceable tiles rather than a single monolithic finish. Each tile should have a panel ID, electrical rating, connector type, mounting detail, seal detail, drainage path, inspection interval, and removal method. The recessed top geometry is ideal for an orderly photovoltaic garden: smooth from a distance, precise up close, and readable in the maintenance manual.

## Lift planning tasks

• Map high-sun surfaces.

• Define panel tiles.

• Route wiring through repeatable channels.

# Phase 12: Energy Storage and Distribution

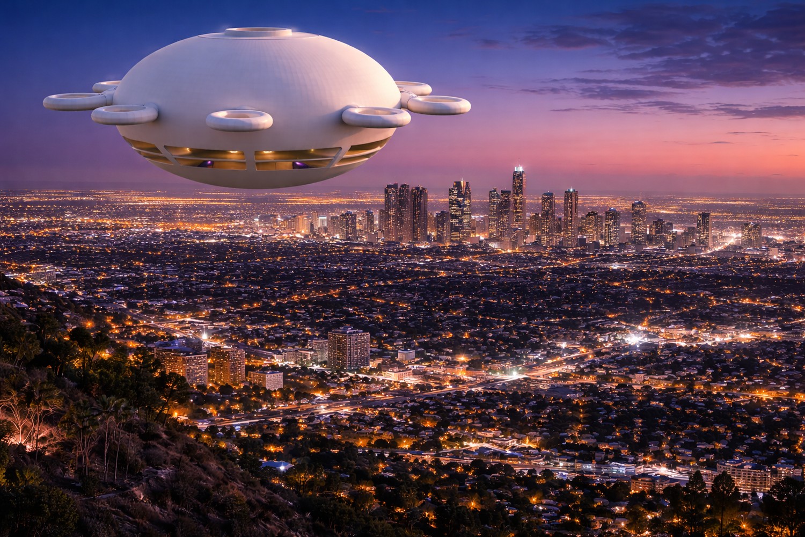
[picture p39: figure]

Lift study: buoyancy volume, mass ledgers, and service access develop together.

A floating home needs a calm electrical backbone: generation, storage, distribution, monitoring, and graceful prioritization. The energy system should be modular by wedge so that improvements can be introduced without redesigning the whole craft.

Phase 12 technical focus: energy storage and distribution should be drawn as a house grid and a flight grid sharing a clear backbone. The source material points toward all-electric operation, graphene ultracapacitor ambitions, and modern storage improvements. Treat storage technology as a replaceable bay: define voltage architecture, cable trays, isolation points, thermal management, monitoring, access doors, and reserved expansion volume.

Build an energy one-line diagram early. Include solar input, charge controllers, storage modules, propulsion buses, cabin buses, lighting, galley loads, communications loads, pumps, sensors, computing, and shore or dock interface. Then create a physical routing drawing so cables, cooling, service panels, and furniture do not collide. A clean electrical architecture will make the AirShip easier to build, inspect, upgrade, and teach.

## Solar skin tasks

• Draw a power one-line diagram.

• Create load categories.

• Prototype a bench-scale microgrid.

# Phase 13: Propulsion and Station Keeping

The eight perimeter modules can express balanced movement in every direction while reinforcing the circular identity. The practical design goal is quiet, efficient, symmetric control that lets the AirShip maneuver gracefully and hold position as a home.

Phase 13 technical focus: propulsion in the source concept is arranged around perimeter thrusters, with discussion of efficient ducted or air-multiplier-like rings rather than traditional exposed propellers. The supplied model already expresses eight circular perimeter assemblies, so use them as the visual and functional basis for thrust, station keeping, low-speed maneuvering, and graceful hovering.

For each perimeter module, define thrust direction, duct diameter, motor bay, service hatch, cable route, sensor location, lighting, vibration isolation, and attachment interface. Create bench tests before flight prototypes: static thrust rig, acoustic reading, temperature run, power draw, duct insert variations, and control response. The rings should read as elegant architecture while behaving as precise maneuvering instruments.

## Energy-system tasks

• Assign thrust modules to perimeter positions.

• Simulate symmetric control cases.

• Design removable service cartridges.

# Phase 14: Autonomy and Navigation

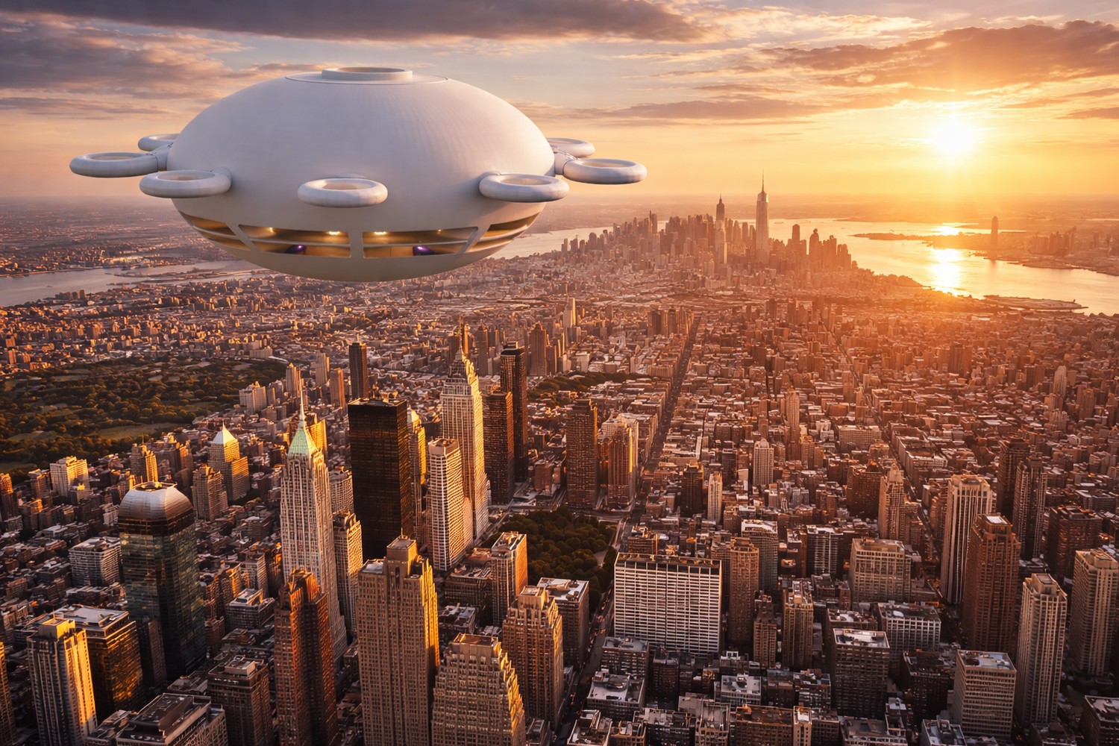
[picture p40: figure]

Energy study: solar skin, storage bays, and distribution routes are planned as one system.

The AirShip should be designed as a calm, sensor-rich home with assisted navigation. Autonomy begins with awareness: position, attitude, altitude, weather data, nearby craft, energy state, and route intent. The first prototypes can focus on observation and stable control.

Phase 14 technical focus: autonomy starts with sensing the world in three dimensions. The transcripts emphasize that automated navigation in open air can be simpler than urban road driving because the vehicle can model airspace, maintain separation, and avoid obstacles with modern sensors. Build the stack around positioning, altitude, inertial data, lidar or depth sensing, cameras, wind estimates, route planning, and human override interfaces.

Create a simulation workflow before building large hardware. The public plan names 3D navigation and blockchain route peer verification; translate that into recorded test routes, sensor logs, digital twin playback, route signatures, and reviewable autonomy decisions. Begin with a small model carrying a phone or sensor pack, then graduate to larger prototypes as the navigation data becomes repeatable.

## Propulsion tasks

• Create a sensor map.

• Build a simulator dashboard.

• Log every test in open format.

# Phase 15: The Mesh Network Node

The AirShip can serve as a beautiful airborne communications node for a privacy-preserving community mesh. Practical builders should focus on lawful, cooperative, open protocols, local resilience, and service to residents, guests, educators, and neighboring craft.

Phase 15 technical focus: the AirShip can also be a network node. The white paper describes a peer-to-peer mesh using ultra-wideband radio concepts, encrypted traffic, frequency agility, blockchain incentives, and real-time data transfer. For a builder guide, convert this vision into hardware bays: radios, antennas, routing computers, storage modules, power conditioning, cooling, maintenance access, and externally documented interface standards.

The uploaded source also frames wireless design as a balance among data rate, distance, speed, number of users, and simultaneous streams. Use that tradeoff as the engineering worksheet for every network prototype. Record antenna placement, line-of-sight assumptions, link budget, packet loss, latency, power draw, enclosure temperature, and firmware version. Network design becomes practical when every flight produces measurable communications data.

## Navigation tasks

• Prototype with permitted radios.

• Document network services.

• Create a resident-friendly connectivity panel.

# Phase 16: Water, Air, and Living Systems

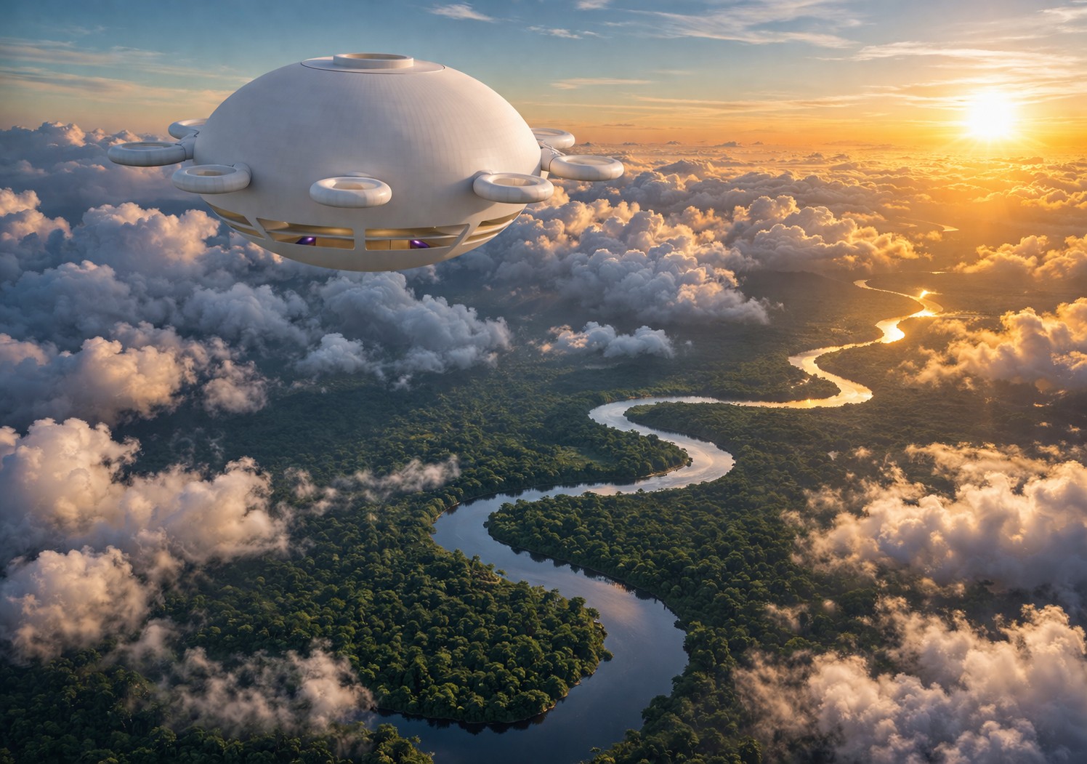
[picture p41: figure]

Autonomy study: sensing, route planning, and digital twin data support graceful navigation.

A floating home feels complete when essentials are abundant and elegant. Water capture, filtration, storage, efficient fixtures, fresh-air exchange, indoor planting, and maintenance access should be designed as visible signs of care.

Phase 16 technical focus: water, air, and living systems should be integrated like a small vessel and a high-end residence. Reserve service volume for potable water, filtration, pumps, greywater treatment, humidity control, ventilation, thermal recovery, air-quality sensors, and maintenance drains. The white paper's abundance language includes water, sewage treatment, electricity, and food, so each utility should have a visible pathway from source to use to recovery.

Create a utilities board before building rooms. Mount representative pumps, valves, tanks, filters, sensors, wiring, and controls on a test panel at human scale. Label every line and measure power draw, noise, service time, and replacement clearance. Then fold the tested layout back into the curved interior so everyday residents see beautiful rooms while maintainers see an intelligible machine.

## Mesh-node tasks

• Create a resource loop diagram.

• Separate potable, grey, and garden water paths.

• Design systems as accessible furniture-like modules.

# Phase 17: Food and Garden Modules

OpenAirShips imagines food abundance alongside mobility. The AirShip home can begin with compact gardens: herbs, greens, seed libraries, mushroom drawers, microgreens, and balcony planters on the sun deck. Larger fleet members can host farms and nurseries.

Phase 17 technical focus: food systems can begin small and become a signature capability. The source plan imagines AirShip FarmBots, permaculture food forests, hydroponic hemp farms, and local production of hemp-based filament. Inside the luxury home, start with compact grow cabinets, herb walls, seed storage, compost experiments, and a small nursery station connected to the water and lighting plan.

For community-scale work, separate residential gardens from production modules. A residential module is quiet, clean, and beautiful. A production module is optimized for tray access, nutrient delivery, robotics, harvesting, drying, seed saving, and fiber processing. Document both. The AirShip becomes more useful when it can host a dinner, teach horticulture, and support material production with the same design language.

## Living-system tasks

• Design a galley garden wall.

• Create seed storage.

• Plan fleet-scale farm variants.

# Phase 18: Waste as Resource

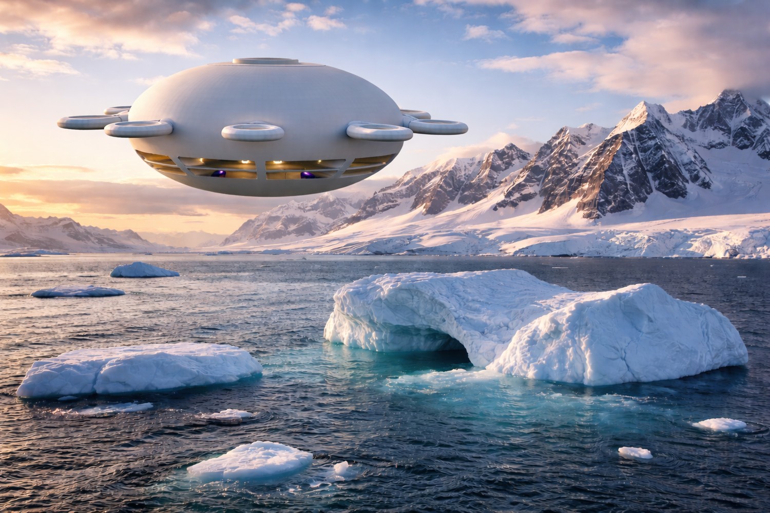
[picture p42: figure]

Living systems study: water, air, power, and comfort are integrated into the home.

A practical society treats outputs as inputs. Organic matter, packaging, worn parts, wash water, and fabrication scraps can be sorted into loops for composting, reuse, repair, recycling, and design improvement.

Phase 18 technical focus: treat every output stream as a design input. Track organic waste, greywater, packaging, print scraps, worn panels, filters, and maintenance parts. The white paper calls for reusable and recyclable materials so outdated designs can be melted down or repurposed; that idea becomes a workshop protocol when parts are labeled by material, revision, mass, and next use.

Build a circular-materials station into the workshop plan: sort bins, wash area, shredder or grinder space, filament testing, sample storage, and a digital inventory. Every failed prototype should still yield geometry lessons, mass data, material behavior, and reusable feedstock. This keeps the project lively and precise: nothing disappears into vague waste, and every experiment improves the next component.

## Garden module tasks

• Create labeled resource stations.

• Design removable collection drawers.

• Track material return rates.

# Phase 19: 3D Printing for Replication

The source vision places 3D printing at the center of growth. The practical starting point is a parts library for non-critical components: interior brackets, covers, handles, planters, ducts, templates, model sections, and educational kits.

Phase 19 technical focus: 3D printing is not merely a way to make parts; in the OpenAirShips vision it is the replication engine. The white paper imagines AirShip printers moving hot ends accurately through space, multiple printer nodes collaborating, and different materials being deposited together. Start with conventional printers for parts, then document the path toward larger robotic fabrication.

Create a print standard for every component: file name, material, layer orientation, infill, reinforcement, surface finish, tolerance, post-processing, test fit, part ID, and replacement interval. For multi-material ambitions, define which elements carry structure, conductivity, sealing, insulation, and finish. A printed AirShip becomes plausible when each part is boringly well documented and delightfully easy to improve.

## Resource-loop tasks

• Start with small printed parts.

• Attach QR codes to part histories.

• Maintain parametric source files.

# Phase 20: The AirShip Workshop

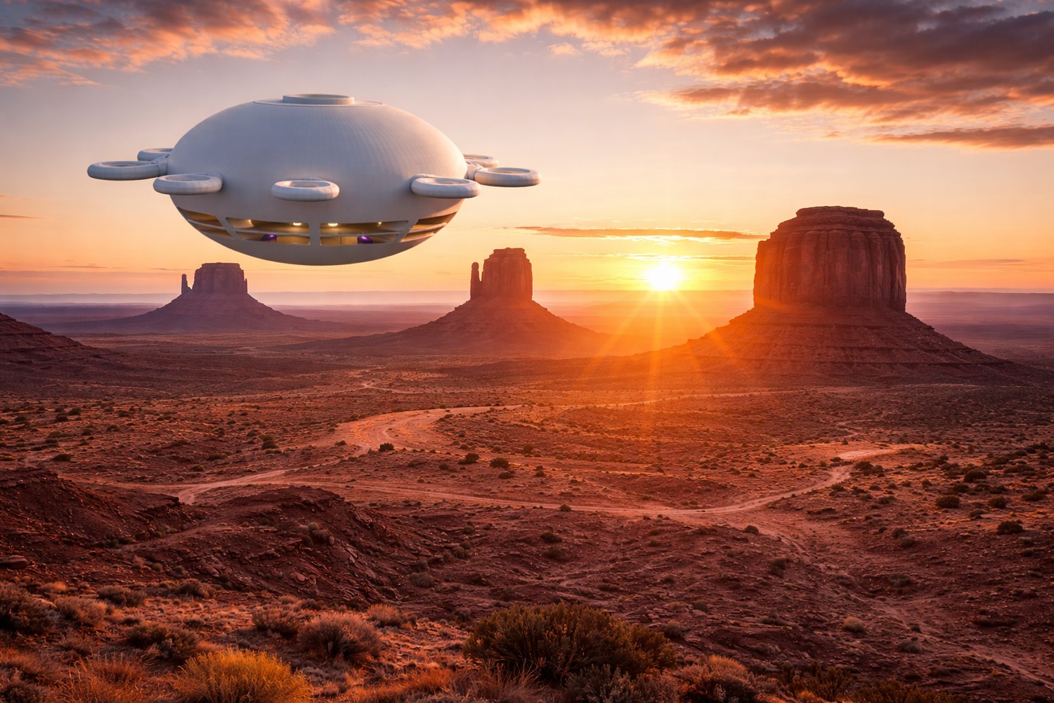
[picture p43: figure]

Resource loop study: materials, print scraps, water, and food systems feed future work.

Every serious build needs a workshop that feels like the future it serves: clean benches, model wall, print farm, materials library, electronics bench, documentation station, and a hospitality area where newcomers can understand the dream in minutes.

Phase 20 technical focus: the workshop is the first physical AirShip system. It should contain CAD stations, printer bays, material storage, assembly benches, coupon testing, electronics benches, photo documentation, packing, and a clean review table for finished parts. The OpenAirShips get-involved page names aeronautical, radio, materials, electrical, blockchain, Linux, encryption, video, and 3D-printing specialists; the room should welcome all of them.

Arrange the workshop around flow: idea, drawing, small print, test coupon, subsystem mockup, review, revision, publication. Put cameras and measurement tools where they are used, not hidden in drawers. A beautiful workshop culture produces beautiful craft because the same care given to a surface finish is given to filenames, labels, checklists, and the way people hand work to each other.

## Replication tasks

• Create zones for CAD, print, assemble, test, document.

• Display the reference model prominently.

• Host weekly open studio hours.

# Phase 21: Prototype Ladder

Move from small to large with grace. The ladder can include desk model, display model, module mockup, interior cabin mockup, sensor gondola, tethered demonstrator, autonomous demonstrator, one-room hull mockup, and full home integration model.

Phase 21 technical focus: prototype in a ladder. The transcript proposes beginning with very small craft, even a test model capable of carrying a phone for remote presence, before moving toward rideable scale. That ladder can be formalized as desktop geometry, buoyancy cell coupon, perimeter duct test, sensor gondola, room mockup, small autonomous demonstrator, one-sector module, and full-scale interior segment.

Each rung should answer one question cleanly. Does the duct make enough thrust? Does the window band feel spacious? Can the stair core be entered comfortably? Does a sensor package hold altitude? Does a printed bracket meet the interface drawing? Do not ask one prototype to prove everything. Let each object be a clear sentence in the larger engineering story.

## Workshop setup tasks

• Define success for each rung.

• Limit each prototype to one main question.

• Publish lessons after each build.

# Phase 22: Digital Twin

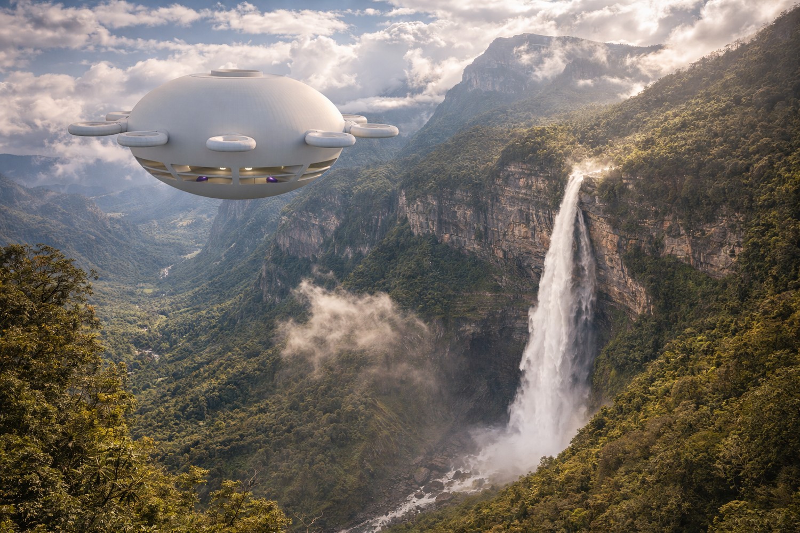
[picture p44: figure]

Workshop study: fabrication, testing, photography, and publication share one space.

A digital twin lets the AirShip evolve as a coordinated system. It can combine CAD, mass estimates, energy models, interior layouts, sensor data, maintenance logs, and community feedback into one living model.

Phase 22 technical focus: the digital twin is the living memory of the build. It should hold geometry, mass, components, wiring, plumbing, energy, sensor data, prototype results, maintenance records, and render-ready scenes. Because OpenAirShips emphasizes open-source iteration, the twin should be legible to new contributors: clean layers, obvious names, linked drawings, and change notes written for humans.

Use the digital twin to compare imagined performance with measured performance. After every print, weigh the part and update the mass ledger. After every bench test, attach power, heat, noise, and fit notes. After every render, record which geometry version produced it. Over time, the twin becomes more than a model; it becomes the shared operating language of the project.

## Prototype tasks

• Choose a shared repository.

• Connect CAD views to requirements.

• Update the twin after every test.

# Phase 23: Review Rituals

The project needs rituals that keep optimism organized. A weekly review can celebrate progress, compare prototypes, update requirements, invite critique as contribution, and keep decisions aligned with the reference atlas.

Phase 23 technical focus: reviews should be structured enough to improve quality and light enough to invite participation. Use four review modes: geometry review, systems review, fabrication review, and story review. Geometry checks the reference body. Systems checks power, lift, water, network, and controls. Fabrication checks whether parts can be made. Story checks whether drawings, images, and text help new builders understand the work.

Give every review a visible output: accepted drawing, open issue, changed dimension, new test, updated render, or clearer paragraph. The best review ritual makes decisions traceable without becoming theatrical. Publish short notes, mark owners, and close the loop. A contributor should be able to join months later and understand not only what was decided, but why the decision made the AirShip easier to build.

## Digital twin tasks

• Open with the vision.

• Review geometry changes first.

• Close with published next steps.

# Phase 24: Documentation as Infrastructure

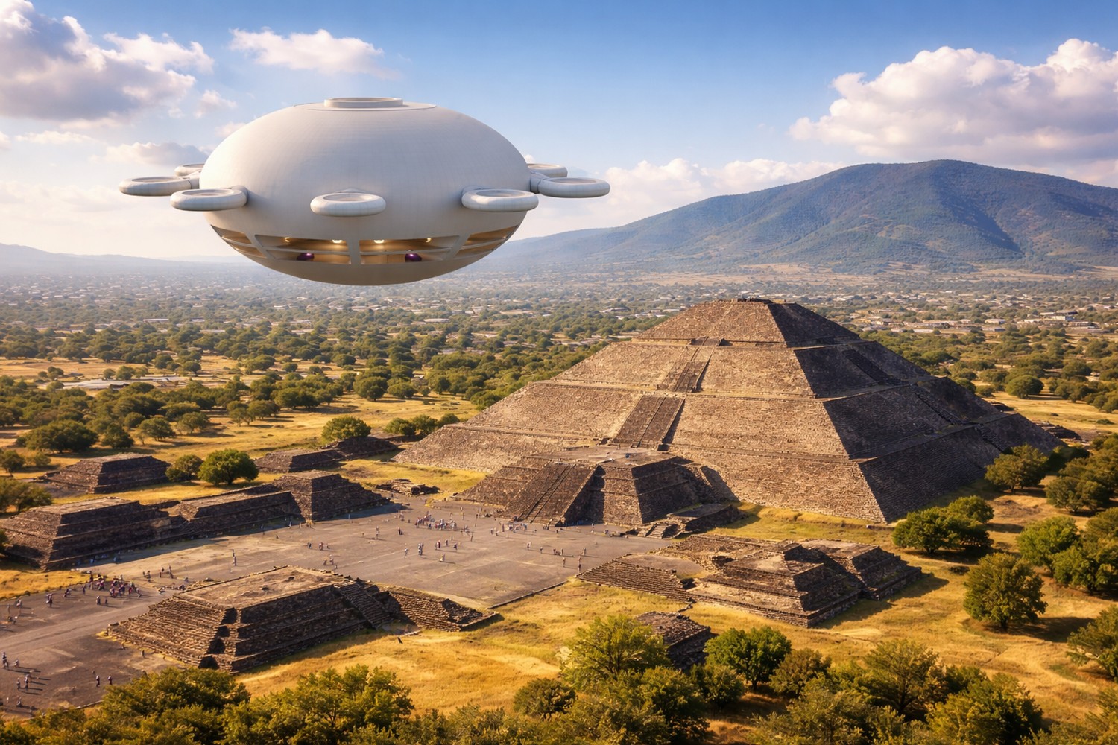
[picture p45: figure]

Digital twin study: CAD, test data, and documentation remain synchronized.

Documentation is not paperwork; it is how the AirShip replicates. Every part, test, decision, material, and room concept should have a page that another builder can follow. Good documentation turns one workshop into a global classroom.

Phase 24 technical focus: documentation is infrastructure. The white paper depends on open replication, and the public site points people toward the plan, white paper, GitHub, and community discussion. Build the document system as if it were a subsystem of the craft: versioned folders, part numbers, diagrams, photos, test reports, meeting notes, source snapshots, contributor credits, and publication checklists.

Use a documentation template for each part and each subsystem. Include purpose, drawing, material, mass, interface, tool requirements, build steps, inspection points, revision history, and next experiments. Good documentation lets a builder in another city reproduce a bracket, improve a duct, translate a page, or spot a better route for a wire without needing to ask for private context.

## Review tasks

• Use templates.

• Photograph every assembly.

• Write for a capable newcomer.

# Phase 25: Open Source Governance

A strong build community needs fair ways to decide. Governance can include proposals, design review boards, resident councils, contributor credits, transparent budgets, and elected maintainers for core modules.

Phase 25 technical focus: open-source governance should make contribution simple and excellence visible. The OpenAirShips open-source page describes commitment to releasing designs and software for public improvement, and the GitHub repository provides a home for shared assets. Define contribution types: CAD, code, renders, tests, writing, outreach, materials research, supplier notes, and workshop lessons.

Create a lightweight governance map: maintainers, reviewers, release managers, issue labels, file standards, design proposals, accepted changes, and archived experiments. Pair freedom with clarity. A contributor should know where to submit a part, how to name it, what evidence supports it, who reviews it, how it becomes official, and where its story appears in the next public release.

## Documentation tasks

• Create proposal formats.

• Publish voting records.

• Reward maintainers and teachers.

# Phase 26: The Contribution Economy

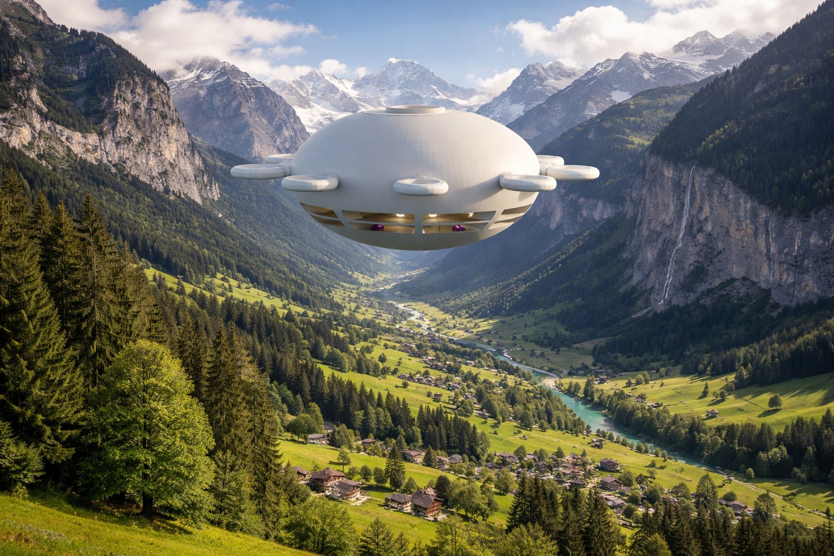
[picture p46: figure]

Documentation study: drawings, photos, revision notes, and part records become infrastructure.

The source materials imagine rewards for useful contributions: transport, housing, printing, food, education, media, governance, storage, and network services. The practical version can start with credits, reputation, grants, bounties, and shared ownership pools.

Phase 26 technical focus: the contribution economy turns useful work into recognized value. The white paper lists many contribution categories: network data transfer, storage, node deployment, development, mapping, transportation, housing, 3D printing, water, electricity, food, seeds, education, governance proposals, voting, media, and exchange. Treat this list as an early service catalog for the AirShip civilization.

Build a ledger prototype before building a token. Record tasks, deliverables, reviewers, evidence, time, materials, and resulting benefit. A 3D printed bracket, a hydroponic tray, a mesh relay test, and a training video can all be logged in the same structure. This keeps the economy grounded in real outputs, real learning, and visible progress rather than abstract enthusiasm.

## Governance tasks

• List contribution categories.

• Define evidence of work.

• Create a public gratitude ledger.

# Phase 27: A Floating Neighborhood

One AirShip is a home. Many AirShips become a neighborhood. The circular form encourages docking clusters, shared sun decks, classroom gatherings, repair exchanges, garden swaps, music nights, and cooperative routing.

Phase 27 technical focus: a floating neighborhood needs spatial rules. Define docking distance, communication protocol, shared service windows, quiet hours, resource exchange points, guest arrival paths, emergency meeting points, and common cultural practices for meals, workshops, education, and maintenance. The AirShip is a home, but a fleet becomes a living district with its own geometry and rhythm.

Draw neighborhood diagrams at several scales: two AirShips visiting, eight AirShips in a circle, a workshop cluster, a garden cluster, a river or bay gathering, and an overland travel formation. Include data links, lighting, water exchange, cargo transfer, social spaces, and service access. A good fleet plan feels like a marina, a campus, and a constellation all at once.

## Contribution-economy tasks

• Design gathering protocols.

• Create shared calendars.

• Map services across the fleet.

# Phase 28: Luxury Without Waste

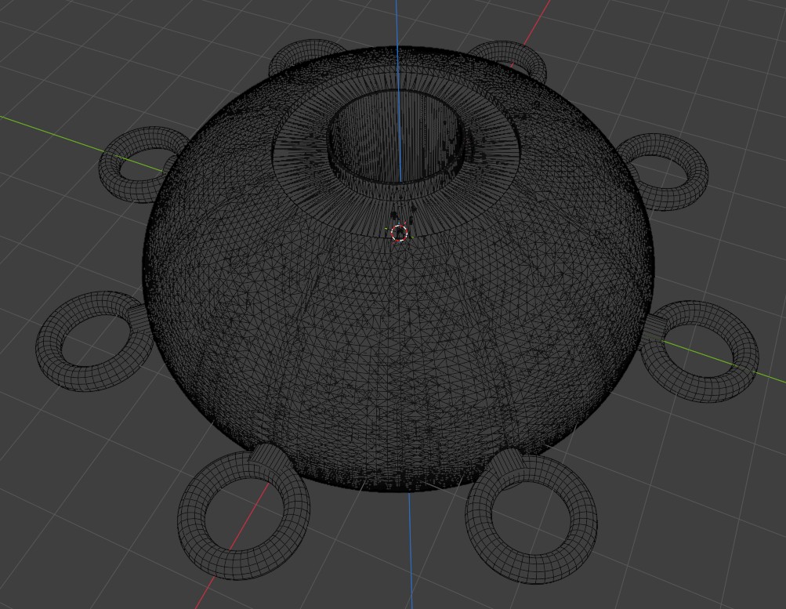
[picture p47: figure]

Contribution study: useful work is recorded, reviewed, credited, and improved.

Luxury in this society is beauty, time, health, movement, learning, and belonging. Interiors can use durable finishes, modular furniture, natural textures, excellent lighting, and quiet systems that make the home feel generous without burden.

Phase 28 technical focus: luxury without waste is a specification. Replace vague luxury with measurable qualities: excellent view lines, quiet sleeping rooms, durable surfaces, thoughtful storage, low-maintenance fixtures, warm lighting, efficient appliances, repairable furniture, and systems hidden behind elegant access panels. The craft should feel rich because every square meter performs beautifully.

Design interior modules as built-in furniture rather than loose objects fighting the curve. Window benches can hold storage. Curved walls can hide ducts. Stair landings can become reading shelves. Galley cabinets can double as structural partitions. The shell geometry is not a limitation; it is the design language that makes the home distinct from apartments, yachts, aircraft, and recreational vehicles.

## Neighborhood tasks

• Design multi-use furniture.

• Choose repairable finishes.

• Use lighting scenes for daily rhythms.

# Phase 29: Education Aboard

Each AirShip can be a school. Residents and guests can learn navigation, gardening, electronics, CAD, cooking, music, languages, repair, governance, and stewardship. Education makes the fleet self-renewing.

Phase 29 technical focus: education aboard should be hands-on and modular. Create lessons around buoyancy, solar power, CAD, 3D printing, water systems, mesh networking, gardening, open-source licensing, rendering, storytelling, and community operations. Each lesson should connect one visible feature of the AirShip to one skill a builder can practice immediately.

Turn every subsystem into a teaching station. A transparent utility panel can explain water flow. A removable solar tile can teach wiring and maintenance. A printed bracket can teach materials and tolerances. A mesh radio bay can teach decentralized networking. A living classroom helps the project recruit skilled contributors because newcomers learn by touching real parts.

## Luxury-detail tasks

• Build a learning wall.

• Host skill circles.

• Create youth-friendly model kits.

# Phase 30: Health and Wellbeing

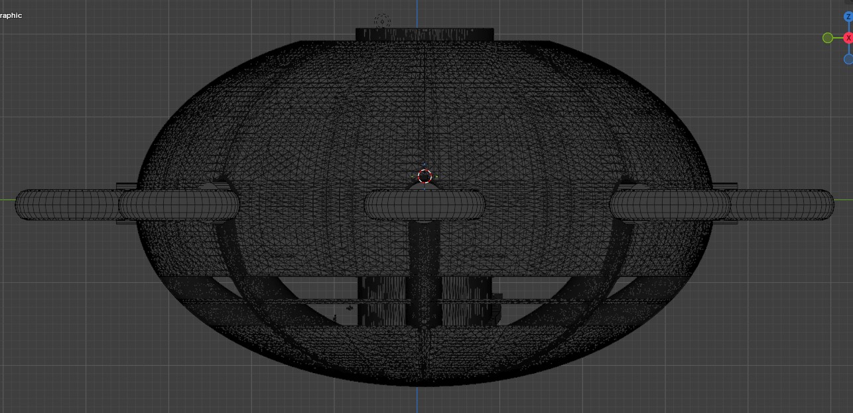
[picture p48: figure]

Luxury study: built-in furniture, warm light, views, and service access shape the interior.

The AirShip home should support sleep, movement, sunlight, fresh meals, quiet work, and community connection. Health is designed through routines as much as hardware: morning deck time, shared meals, creative work, garden care, and evening observation.

Phase 30 technical focus: health and wellbeing are layout decisions. Prioritize daylight, clean air, low noise, comfortable sleeping, gentle circulation, access to plants, places for exercise, social dining, quiet work, and views of land, water, and sky. The AirShip should allow a household to live slowly while the craft moves elegantly through space.

Create a wellbeing schedule for the design: morning light at breakfast, shaded work zones at midday, quiet evening cabins, night lighting that preserves calm, and fresh-air paths that do not disturb sleeping areas. Measure comfort with mockups and occupant notes. A home in the air succeeds when residents forget the complexity of the machine and remember the grace of the day.

## Education tasks

• Plan wellness zones.

• Use circadian lighting.

• Create daily care rituals.

# Phase 31: Art Direction

Reference OpenAirShips.com for additional art ideas, model lineage, and blueprint inspiration. The visual language should be optimistic: white hull, soft solar surfaces, warm interiors, luminous windows, green decks, and radial geometry.

Phase 31 technical focus: art direction must protect the recognizable model while improving finish, texture, color, light, and storytelling. Use the supplied renders as environment studies: coastline, clouds, desert, jungle, city, snow, valley, and water. The AirShip should keep its circular body, central top opening, perimeter rings, and two-floor side band while materials and lighting create variety.

Create an art bible with render angles, lens choices, daylight palettes, surface finishes, interior warmth, window glow, panel pattern, scale cues, and human presence. Include OpenAirShips.com as the reference hub for further art ideas, public assets, and technical context. The goal is a visual identity that makes the craft instantly recognizable across every image, blueprint, animation, and poster.

## Wellbeing tasks

• Create a mood board.

• Render the same shape in multiple environments.

• Maintain visual continuity across all renders.

# Phase 32: Blueprint Package

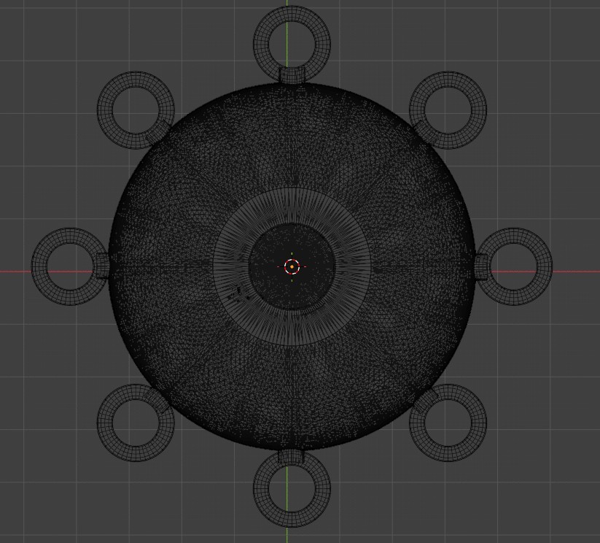
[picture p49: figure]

Health study: daylight, quiet rooms, clean air, and plants make the craft livable.

The blueprint package should be a growing set of views: locked exterior, plan, section, module, floor layout, access core, solar map, power map, network map, water loop, interior elevations, and fleet docking diagrams.

Phase 32 technical focus: the blueprint package should contain enough information to guide a serious builder from concept to prototype. Include general arrangement, top plan, side elevations, underside view, section cuts, wedge module drawing, central core drawing, floor layouts, utilities diagrams, energy one-line, mesh-node diagram, propulsion module diagram, materials matrix, and prototype ladder.

Make every blueprint page earn its place. Add scale bars, orientation markers, part labels, revision number, author, source file, and inspection notes. Separate presentation drawings from fabrication drawings. A presentation page sells the vision; a fabrication page tells a builder what to make, where it fits, how it connects, and what evidence proves it works.

## Art-direction tasks

• Start with reference views.

• Add dimensions only after expert review.

• Version every sheet.

# Phase 33: Full-Scale Interior Mockup

Before building a full craft, build rooms. A full-scale slice can test ceiling heights, window placement, stairs, furniture, storage, lighting, mechanical access, and emotional comfort inside the reference envelope.

Phase 33 technical focus: a full-scale interior mockup is the bridge between beautiful renders and livable architecture. Build one curved wall bay, one window band section, one floor transition, one storage module, one service panel, and one stair segment. Use inexpensive materials first, but match dimensions, sight lines, handle positions, lighting levels, and seating heights.

Run the mockup like a small apartment. Prepare a meal, sit with a laptop, store luggage, open panels, move through the stair, and host a conversation. Photograph every posture and every awkward reach. Then revise the CAD. This is where luxury becomes physical: a hand lands naturally, a cabinet opens cleanly, and a view frames the horizon.

## Blueprint tasks

• Mock up one radial slice.

• Invite walkthroughs.

• Record resident feedback.

# Phase 34: Model-Based Fabrication

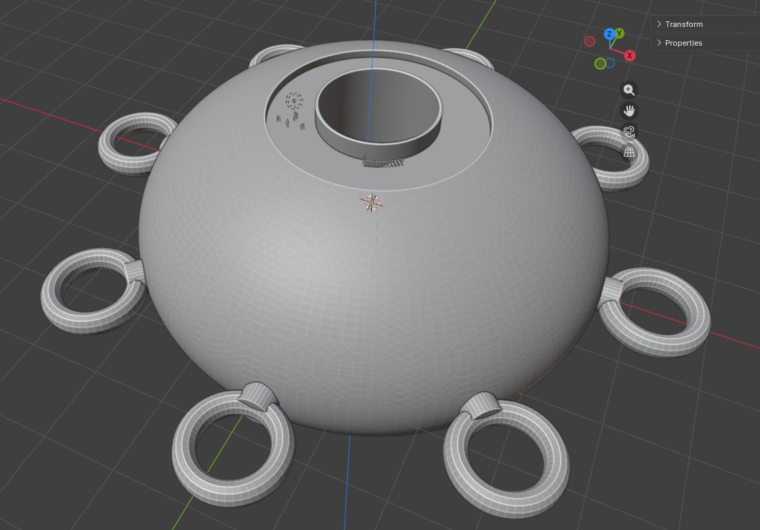
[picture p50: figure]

Blueprint study: controlled drawings translate the model into build packets.

Fabrication should flow from the digital twin to jigs, templates, molds, printed parts, and assembly instructions. A builder can begin with display-scale models, then move to full-scale interior components and non-flight exterior panels.

Phase 34 technical focus: model-based fabrication means the model is the source of truth. Parts should be generated from the controlled CAD atlas, exported in standard formats, labeled by revision, and checked against the physical part after fabrication. When the same geometry produces drawings, renders, prints, and inspection templates, the build becomes faster and more trustworthy.

Define fabrication packets for hull panels, ring modules, brackets, ducts, interior modules, and utility boards. Each packet should include model file, drawing PDF, print or fabrication settings, material, expected mass, tolerance, surface finish, assembly sequence, and photo checklist. A builder should be able to open one packet and know exactly how that part contributes to the whole craft.

## Mockup tasks

• Create printable templates.

• Mark parts with orientation.

• Use assembly photos in the build manual.

# Phase 35: Systems Integration Day

Choose regular integration days where teams connect their work: power with interiors, water with structure, controls with propulsion, solar with maintenance access, network with resident interface. Integration turns separate inventions into a home.

Phase 35 technical focus: systems integration day is a rehearsal for the complete AirShip. Bring power, controls, sensors, water, lighting, communications, and mechanical assemblies together on benches and mockups before they enter the hull. Integration should expose interface needs: connectors, access doors, labeling, mounting plates, software versions, calibration steps, and spare parts.

Write an integration script with start state, steps, expected readings, photos to capture, and sign-off criteria. Power the cabin lights, run a pump, boot the mesh node, spin a ducted fan on the bench, log sensor data, and update the digital twin. The day should end with fewer mysteries and a clearer bill of materials.

## Fabrication tasks

• Bring physical parts to the same table.

• Review interfaces.

• Publish updated diagrams.

# Phase 36: Community Workshop Curriculum

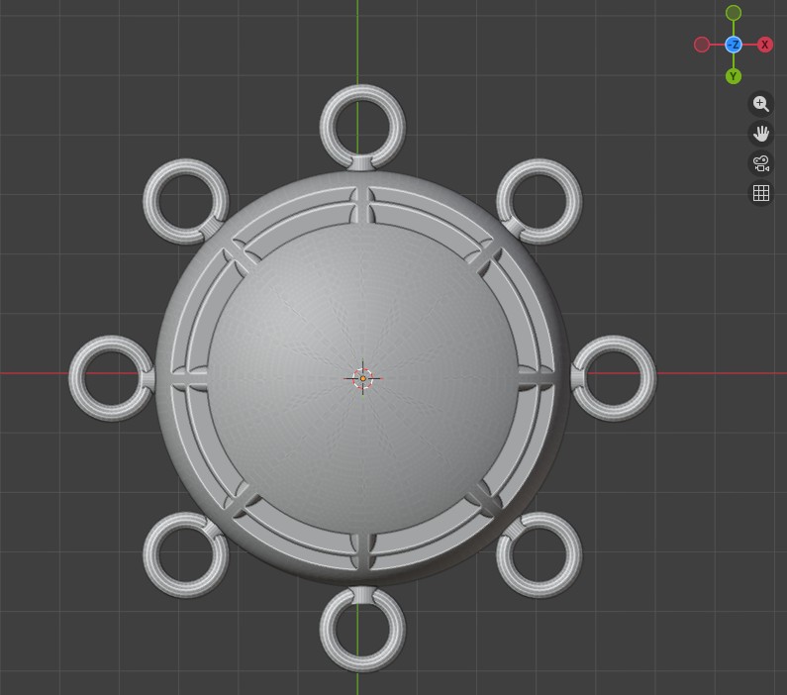
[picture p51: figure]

Fabrication study: model-based parts move from CAD to printed components.

A practical project invites people in. Build a curriculum that teaches the AirShip idea in one afternoon: model tour, modular wedges, solar skin, garden loop, mesh node, interior mockup, and contribution opportunities.

Phase 36 technical focus: the community workshop curriculum should be a builder pathway. Start with AirShip geometry and source history, then teach CAD basics, model naming, 3D printing, material coupons, solar tiles, simple circuits, mesh networking, interior mockups, rendering, documentation, and open-source contribution. Each class should produce a visible artifact for the shared library.

Organize workshops by skill level. Beginners label model features and assemble simple parts. Intermediate builders test brackets, document materials, and improve diagrams. Advanced contributors work on simulations, controls, radio hardware, energy systems, and structural analysis. The curriculum turns spectators into contributors by giving everyone a practical door into the project.

## Integration tasks

• Create slides and handouts.

• Offer beginner tasks.

• Record sessions for remote builders.

# Phase 37: Funding the Dream

Funding should match the ethos: transparent, milestone-based, community-owned where possible, and tied to visible prototypes. Supporters should see exactly what their contribution creates, from model refinement to room mockups to sensor benches.

Phase 37 technical focus: funding should be tied to milestones that produce durable assets. Fund a CAD cleanup, a model atlas, a perimeter duct prototype, a solar tile mockup, a full-scale window bay, a mesh-node bench test, a material coupon library, a documentary short, or a public blueprint release. Each milestone should leave behind files, photos, data, and a reusable lesson.

Create a funding board with budget, supplier list, owner, deliverable, publication date, and follow-up test. The OpenAirShips history includes an early crowdfunding attempt; the next version can make support tangible by showing exactly what a contribution builds. People support a dream more easily when the next artifact is specific, beautiful, and useful.

## Curriculum tasks

• Publish milestone budgets.

• Show prototype photos.

• Offer contributor credits and open access.

# Phase 38: Partnerships

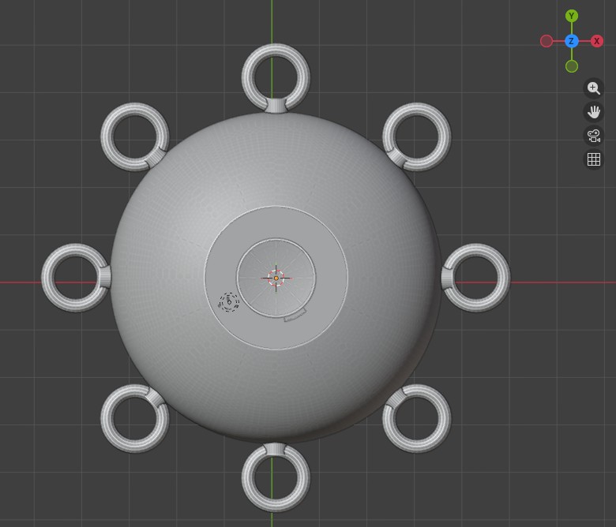
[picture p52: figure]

Fleet study: homes, workshops, gardens, relays, and classrooms share the same design family.

The AirShip needs friends: universities, makerspaces, aeronautical engineers, materials labs, solar designers, interior architects, permaculture teachers, open-source communities, and artists. Partnerships turn a single dream into a civilization-scale craft tradition.

Phase 38 technical focus: partnerships should map to missing capabilities. The public site lists specialist needs including aeronautical engineers, radio hardware engineers, materials scientists, electrical engineers, blockchain coders, Linux programmers, encryption experts, 3D printing experts, video production, and airspace consultants. Use that list as a practical recruiting map for labs, makerspaces, universities, suppliers, and independent builders.

Prepare partner packets rather than general pitches. A materials lab gets coupon requirements. A radio specialist gets mesh-node questions. A design school gets interior mockups and renders. A makerspace gets printable brackets. An electrical engineer gets the energy one-line. Clear packets respect expert time and turn outside interest into useful, credited contributions.

## Funding tasks

• Create a partner map.

• Write invitation letters.

• Define shared deliverables.

# Phase 39: Beautiful Interfaces

Residents should not need to understand every system to live well. The interface can show energy, water, air, garden, route, community messages, maintenance prompts, and learning opportunities in a warm, simple dashboard.

Phase 39 technical focus: interfaces make advanced systems livable. Residents should see calm dashboards for power, water, air quality, route, network status, maintenance reminders, cabin comfort, and community exchange. Technicians should see deeper diagnostic pages with sensor readings, logs, firmware versions, connector maps, and test routines. The same system can be graceful for residents and exact for builders.

Prototype interfaces with paper screens first, then clickable mockups, then live data from bench systems. Avoid visual clutter. Use clear states, large labels, plain language, and beautiful status views. The interface should feel like the instrument panel of a floating home, not a laboratory console, while still giving engineers the detail needed to keep improving every subsystem.

## Partnership tasks

• Prototype a wall display.

• Use plain language.

• Add celebration signals for abundance.

# Phase 40: Fleet Services

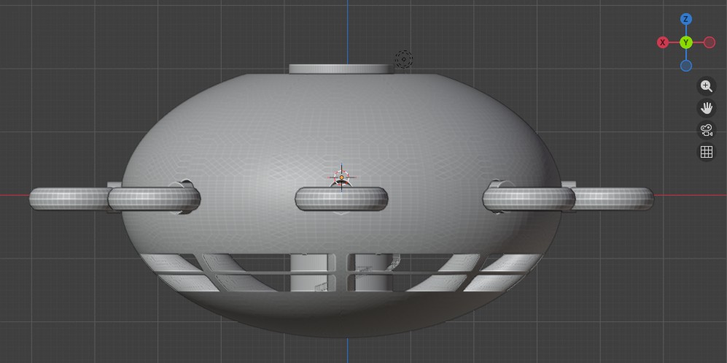
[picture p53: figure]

Research study: primary sources, public pages, and test data stay organized for future builders.

A society of AirShips can specialize. Some craft can be homes, some farms, some clinics, some classrooms, some fabrication shops, some guest houses, some theaters, some relay nodes, and some repair docks.

Phase 40 technical focus: fleet services turn individual homes into a network of capabilities. Define service roles: housing, guest hospitality, mobile workshop, garden module, print shop, water processing, energy support, communications relay, classroom, studio, clinic room, and cargo bay. The white paper's contribution list already contains many of these functions; the builder guide should assign spatial and technical requirements to each one.

Make fleet services modular. A workshop AirShip needs tool storage, benches, dust management, printers, parts library, and extra power. A garden AirShip needs trays, water, nutrients, lighting, harvesting, and seed storage. A relay AirShip needs antennas, routers, energy reserves, cooling, and diagnostics. Shared geometry lets different service craft feel like members of the same family.

## Interface tasks

• Define service archetypes.

• Keep the common hull language.

• Create exchange protocols.

# Phase 41: Docking and Hospitality

The perimeter rings suggest social architecture. They can become docking symbols, guest entry points, transfer ports, observation loops, or service nodes. Design them as places of welcome and graceful exchange.

Phase 41 technical focus: docking and hospitality are where engineering meets manners. Define how people arrive, where they step, what they hold, where luggage goes, how hosts greet guests, how service crews access panels, and how two craft exchange supplies. The white paper imagines traversal between AirShips through top and bottom access, so docking drawings should include vertical and horizontal arrival scenarios.

Build a hospitality storyboard. Show arrival lights, hatch opening, stair sequence, greeting area, shoe and bag storage, guest orientation, meal service, sleeping arrangements, and departure. Then make technical drawings for handholds, thresholds, lighting, signage, intercom, docking guides, and cargo handoff. A great AirShip makes arrival feel effortless because the choreography has been designed.

## Fleet-service tasks

• Map guest arrival flows.

• Design signage.

• Create shared etiquette cards.

# Phase 42: Stewardship Governance

A flourishing society is built through daily habits: open books, respectful meetings, shared learning, restorative conflict practices, resident councils, child-friendly participation, elder respect, and contribution paths for many abilities.

Phase 42 technical focus: stewardship governance keeps the project coherent as it grows. Define who maintains the master model, who approves releases, who reviews tests, who credits contributors, who archives old ideas, who publishes public updates, and who keeps the workshop safe, orderly, and welcoming. Governance should be visible in templates, calendars, labels, and release notes.

Create three recurring documents: the monthly release note, the open issues board, and the build journal digest. The release note shows what changed. The issue board shows what needs help. The digest tells the story of the work in plain language. Together they let the community scale without losing the practical beauty of the original craft.

## Docking tasks

• Write a community charter.

• Create rotating steward roles.

• Celebrate useful work publicly.

# Sources and Continuing Research

Core source documents used for this guide include the supplied OpenAirShips white paper, the supplied AirShip transcripts, and the four supplied model views. The public OpenAirShips.com page describes the goal as low-cost housing and transportation and the plan as small, modular, open-source, 3D-printable autonomous AirShips that scale using off-the-shelf components.

Recommended continuing research streams: OpenAirShips.com for project art, files, and community direction; the OpenAirShips GitHub for project repository material; public 3D model repositories for visual study; airship history archives for precedent; current lighter-than-air research for state-of-the-art design language; and professional aeronautical, materials, electrical, and habitat-design references for engineering development.

Keep source notes positive and useful. The goal of research is not to copy the past, but to gather enough wisdom to build a beautiful future with confidence and clarity.

## Stewardship tasks

• Save source snapshots with dates.

• Credit every contributor.

• Update the blueprint package whenever a source improves the build.

Source foundation: supplied OpenAirShips white paper and video transcripts, supplied model screenshots and wireframes, and OpenAirShips.com for additional art ideas, blueprint context, and continuing technical research.

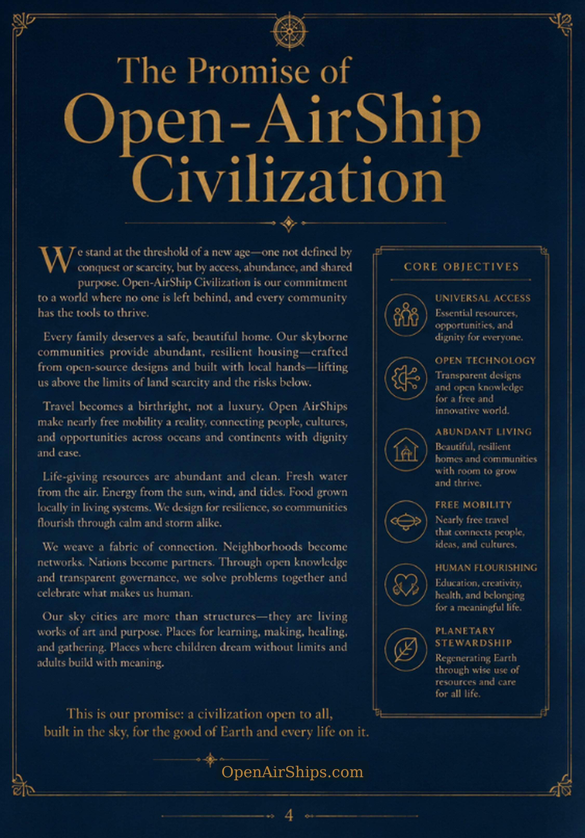
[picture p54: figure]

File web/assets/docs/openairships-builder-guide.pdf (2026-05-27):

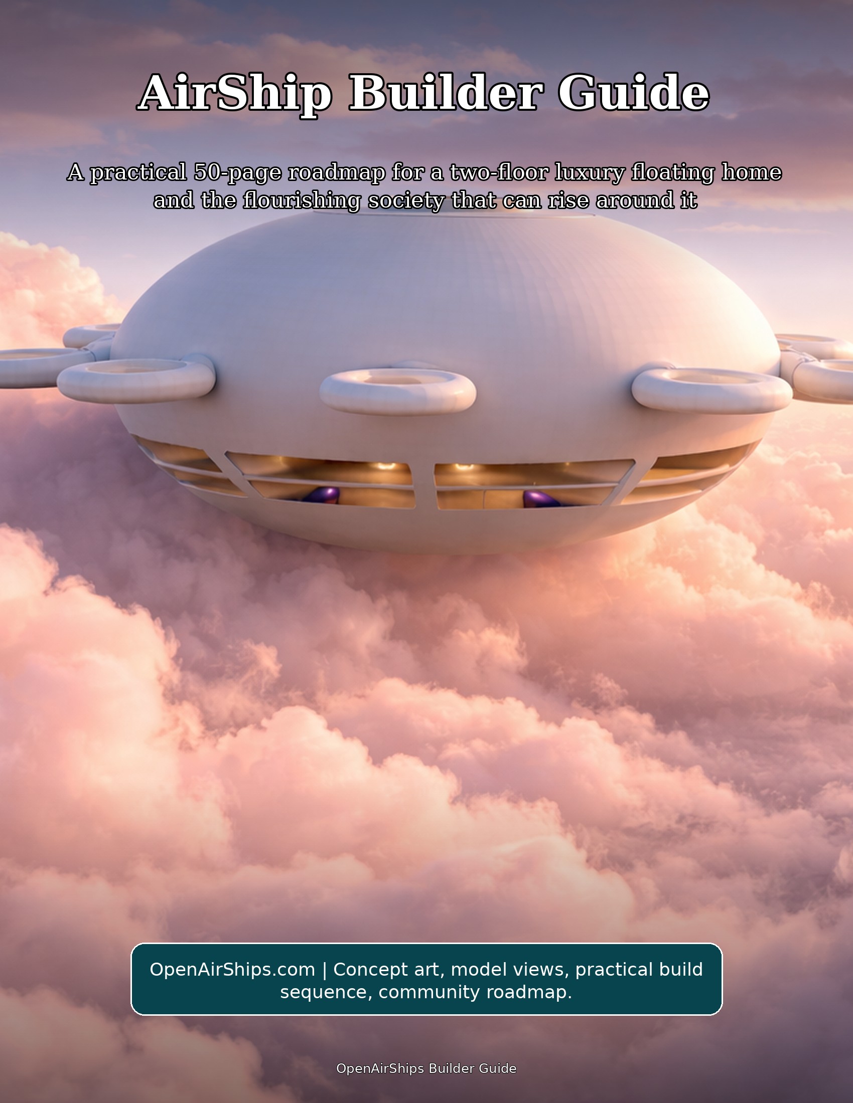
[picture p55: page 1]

# How to Read This Guide

This guide is written for a future AirShip builder who wants a practical path from vision to working prototype. The craft is treated as a round, low-profile, modular, two-floor luxury floating home, with its broad circular hull, upper sun-deck opening, eight perimeter assemblies, and visible two-floor interior band serving as the central design reference.
The pages are arranged as a builder journey. First, they define the spirit and geometry. Then they move into team formation, digital modeling, material research, interior planning, lift architecture, solar power, controls, community economics, food systems, and the flourishing society that can grow around a fleet of beautiful homes in the sky.
The guide stays practical by design. It focuses on constructive action, clear roles, prototyping discipline, open documentation, shared abundance, and graceful iteration. Whenever the work requires deep specialization, the practical step is to invite the right expert into the build circle and make their contribution part of the open design commons.
Workshop actions
- Print the reference-geometry pages and keep them in the workshop.
- Name a documentation steward responsible for keeping the reference atlas current.
- Create a shared build journal before any CAD changes are proposed.

# The Promise of the AirShip Home

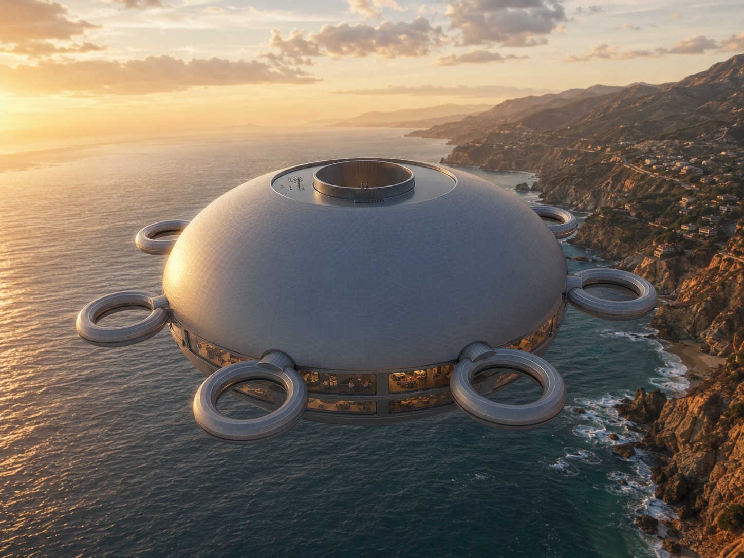
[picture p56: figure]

Hero concept view: the reference AirShip presented as a two-floor floating home. “Build the home as if every curve is an invitation: to travel lightly, live beautifully, and help others rise with you.”
An AirShip home is more than a vehicle. It is a calm, solar-facing dwelling that carries household life into three-dimensional space. The supplied model already expresses a distinct promise: a broad circular hull, eight symmetrical docking and propulsion points, an upper sun-deck opening, and a visible two-floor interior band in the x-axis view.
The practical ambition is a floating home that feels luxurious because it is spacious, quiet, resource-aware, and community-connected. Luxury here does not mean excess. It means good light, generous air, open views, elegant circulation, durable materials, resilient power, and rooms designed for rest, study, cooking, growing, and gathering.
The social ambition is equally important. The AirShip becomes a node in a new culture of mobility and mutual aid: homes that can gather, separate, exchange resources, host guests, teach skills, grow food, print components, and share knowledge across a living network.

# Reference Geometry and Modular Identity

The supplied model defines the project's reference geometry. The round plan, smooth dome, low vertical profile, two-floor side band, and eight perimeter assemblies form the visual and functional identity of the AirShip.
Design work begins with the existing envelope. Engineering, interiors, systems, service spaces, and finish details can be developed as coordinated layers inside a recognizable platform that can be studied, tested, fabricated, repaired, and celebrated as a coherent family of craft.
A shared reference model makes collaboration easier. Every contributor can work from a common origin, common axes, common modular wedge logic, and common reference views. This keeps design conversations focused on refinement, documentation, and elegant execution.
Foundation tasks
- Freeze the master hull mesh in a read-only archive.
- Create derivative layers only for internal systems, panels, furniture, utilities, and documentation.
- Use revision names that distinguish production work from exploratory sketches.

# Reading the Supplied Views

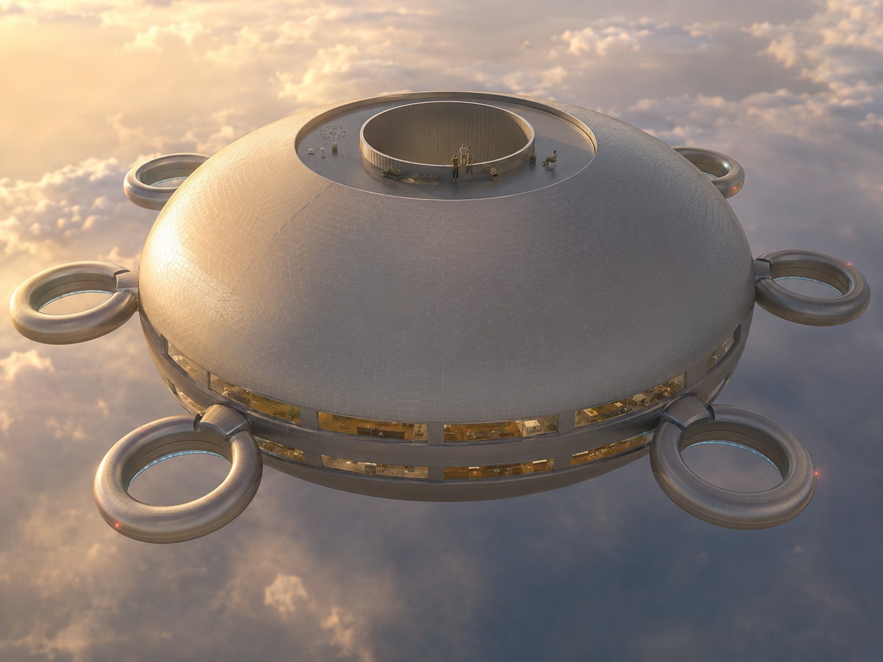
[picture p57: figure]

Reference view: central access ring, smooth upper hull, and perimeter modules.
The perspective view shows the craft as a smooth, broad, rounded body with a recessed upper zone and a central cylindrical access opening. The top views reveal radial symmetry and the ring modules around the circumference. The side view reveals the crucial two-floor band: upper living volume above, lower service and living volume below, with windows or bays distributed across the horizontal axis.
A builder should translate these views into a design atlas. Each view becomes a control drawing: top plan for module spacing, side view for floor separation, perspective view for character, and underside or alternate top view for access and maintenance interpretation. This atlas can be used in every design review.
The most practical first step is not cutting material. It is naming every visible feature. Once the features have names, builders can assign owners, create checklists, and develop prototypes without arguing about what the geometry means.
Geometry tasks
- Label the eight perimeter modules clockwise as P1 through P8.
- Label the upper access ring, recessed solar field, outer hull shell, two floor band, lower service zone, and interior stair core.
- Create a one-page visual glossary and include it in every build packet.

# OpenAirShips Design Lineage

The OpenAirShips source documents describe a modular, open-source AirShip vision built around circular sections, low-cost iteration, solar power, 3D printing, mesh networking, and a society of mutual provision. The public OpenAirShips.com overview also frames the project around small modular open-source autonomous AirShips that can scale toward travel, housing, electricity, internet, clean water, and abundance.
The important builder lesson is that the AirShip is a platform, not a single product. A platform can host homes, workshops, gardens, sensors, routers, classrooms, guest spaces, water systems, and creative studios. That is why modularity matters: the same outer form can support many interior missions.
The practical path is to honor the source idea while making it buildable. Translate the vision into staged prototypes, documented subsystems, community review, and repeatable fabrication recipes that align with the reference geometry.
View-study tasks
- Create a source folder with the white paper, transcripts, screenshots, public site snapshots, and model files.
- Separate vision statements from engineering requirements so both can thrive.
- Turn each recurring idea into a build track: hull, lift, power, interior, controls, network, society.

# The Builder Mindset

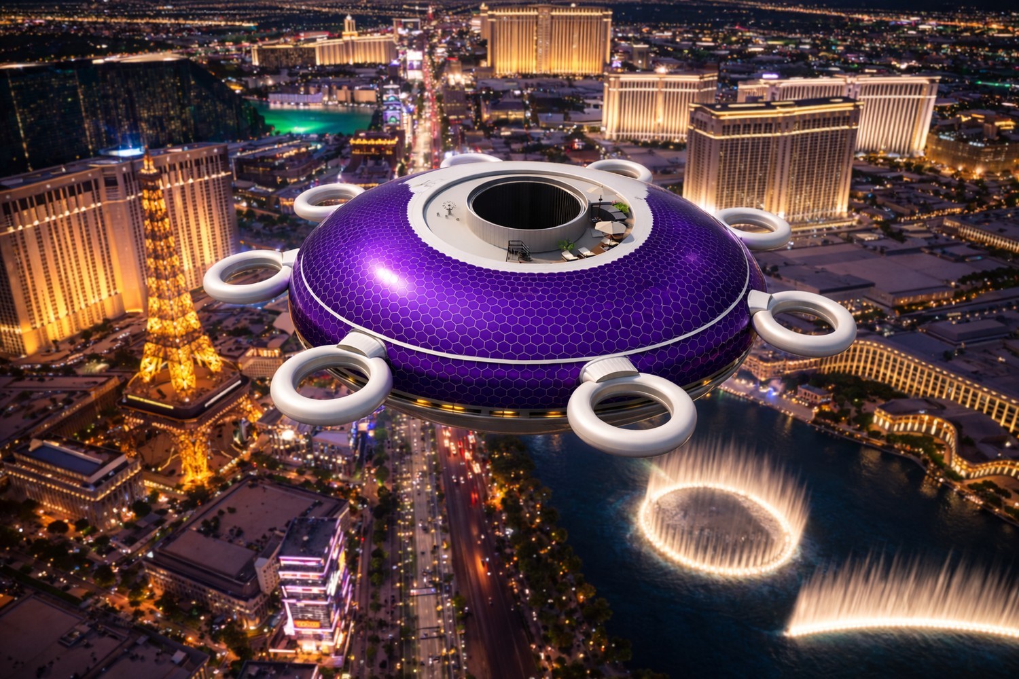
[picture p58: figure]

Concept lineage: OpenAirShips ideas translated into a practical build language.
A potential AirShip builder needs three virtues: patience with iteration, generosity with knowledge, and devotion to elegant execution. The work becomes joyful when each prototype is treated as a contribution to the shared future rather than a private secret.
The best builder mindset is both artistic and empirical. The model has a poetic presence, but the path to flight, comfort, and long service life is a careful sequence of drawings, simulations, small models, subsystem benches, full-scale mockups, and community reviews. Every stage should produce something useful: a diagram, a test result, a part library, a training note, or a better question. The builder should also think like a host. This is a luxury floating home. People will sleep, cook, bathe, work, learn, welcome guests, and look out over changing horizons. The craft should make everyday life feel grounded even while it floats.
Source-library tasks
- Write a one-page builder oath centered on beauty, openness, comfort, and service.
- Choose a weekly design rhythm: review, prototype, document, publish.
- Make every meeting end with one visible improvement to the shared build library.

# Phase 1: Assemble the Circle

Form the first build circle around clear roles rather than vague enthusiasm. The minimum circle includes a project steward, geometry steward, CAD lead, aeronautical advisor, materials advisor, electrical systems lead, interiors lead, controls lead, documentation lead, and community coordinator. Each person owns a track while still contributing to the whole.
In practice, this means treating the AirShip as both artifact and institution. The artifact is the AirShip home; the institution is the open community that keeps improving it. Each page of the build journal should therefore answer two questions: what did we make, and how does it help people live more freely, comfortably, and cooperatively?
A builder who follows this approach will always have a next action. The action may be a drawing, a phone call, a prototype, a meeting, a material sample, a render, a checklist, or a lesson. Small, visible steps create the trust required for a large and inspiring build.
Builder habits
- Publish role cards.
- Host a model walkthrough.
- Create an open decision log.

# Phase 2: Create the Master CAD Atlas

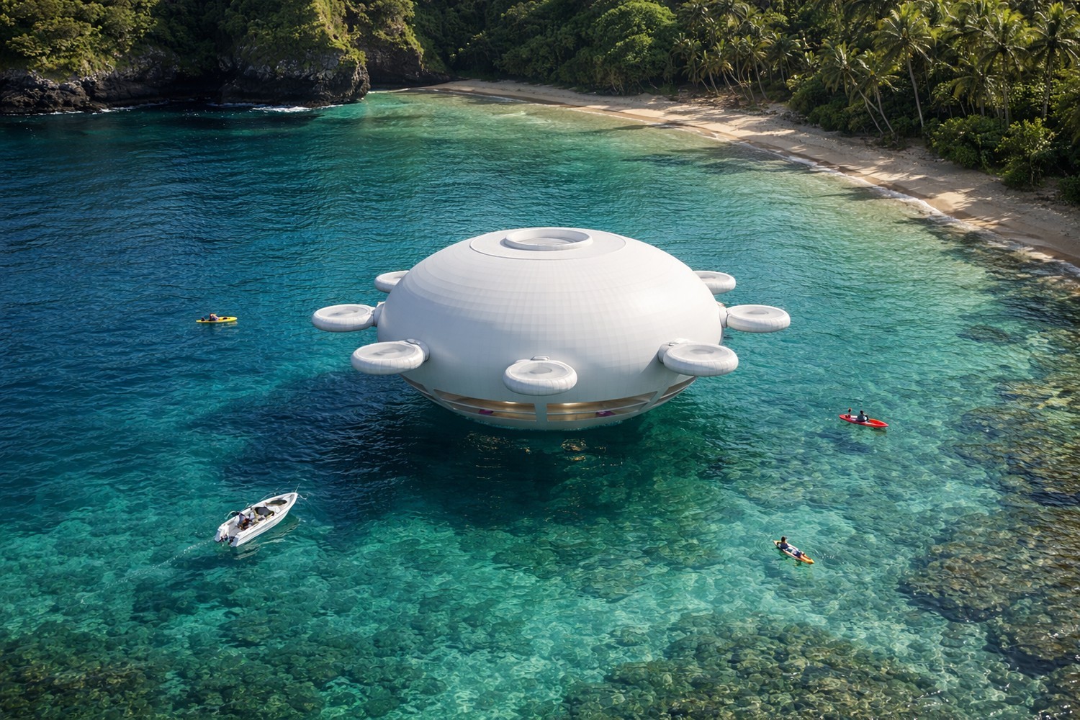
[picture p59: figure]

Workshop image: the builder mindset turns geometry, craft, and documentation into one habit.
The CAD atlas converts screenshots and model files into shared references. It should include top, side, perspective, section, interior, and module views. The key principle is that the exterior hull remains locked while internal structure and systems gain more definition.
Phase 2 technical focus: convert every supplied view into a controlled CAD reference. Use a common origin at the visual center of the craft, align the vertical axis through the central cylinder, and create locked reference planes for top, side, underside, and perspective views. Establish a naming scheme for hull shell, upper access ring, two-floor band, lower service bay, perimeter modules, and internal core so every contributor can attach work to the same coordinate system.
Build the atlas as a package rather than a single file: master mesh, simplified collision model, presentation model, fabrication model, section cuts, and exploded modules. Keep a revision register with author, date, purpose, affected subsystem, and export format. The public OpenAirShips plan calls for repeated global iterative open source revision, so the CAD archive should make comparison, rollback, remixing, and review effortless.
Circle launch tasks
- Archive original files.
- Define axes and origin.
- Create non-destructive layers.

# Phase 3: Wedge-Based Modularity

The circular body naturally invites radial wedge modules. A wedge can hold structure, buoyancy volume, utilities, cabin zones, storage, or service access while sharing the same geometry with its neighbors. Repetition lowers complexity and makes the AirShip easier to teach, print, inspect, and repair.
Phase 3 technical focus: use the circular plan as a manufacturing advantage. Divide the craft into equal radial sectors, each with shared interface geometry for structure, utilities, buoyancy service, inspection access, and interior fit-out. The white paper emphasizes homogeneous circular sections because one tested wedge can inform the next seven, reducing the number of unique molds, tools, checks, and assembly procedures required for a full hull.
For each wedge, document hard points, wire chases, duct paths, panel seams, fastener families, service covers, and allowable interior attachments. A good module standard includes a drawing, a bill of materials, print orientation notes, joining details, access clearances, and a lightweight inspection checklist. Once the wedge interface is stable, the team can improve individual components without reopening the entire craft design.
CAD atlas tasks
- Divide the plan into equal sectors.
- Assign module interfaces.
- Prototype one wedge before multiplying it.

# Phase 4: The Two-Floor Luxury Plan

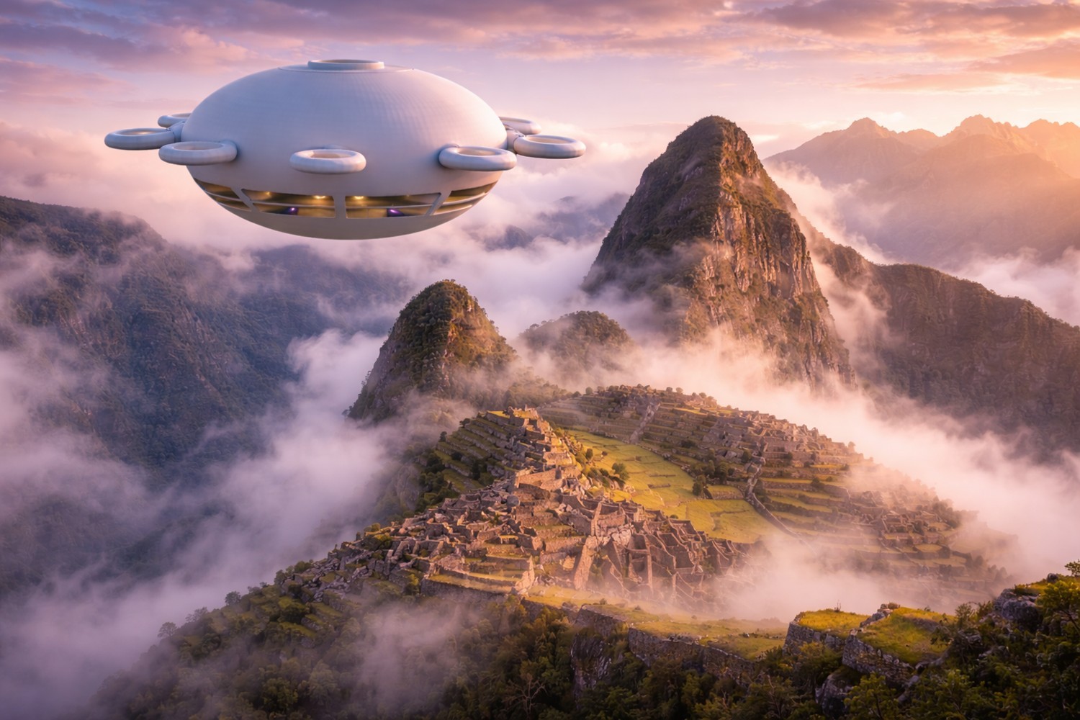
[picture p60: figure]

CAD reference: top, side, and perspective views become the shared atlas.
The side view shows the AirShip as a two-floor floating home. The upper floor can celebrate light, views, cooking, dining, social space, and the sun-deck connection. The lower floor can host private suites, water systems, quiet workrooms, storage, and service corridors.
Phase 4 technical focus: treat the visible side band as the planning datum for two complete living levels. The upper deck can prioritize panoramic social space, galley, dining, work tables, and direct access to the sun-deck core. The lower deck can carry sleeping cabins, quiet rooms, storage, mechanical closets, water systems, sanitation, and service corridors arranged around the same central circulation spine.
Develop the interior as concentric zones. The central core carries stairs, vertical utilities, shared equipment, and the hatch sequence. The middle ring holds daily living functions. The outer ring captures the best views with long windows, built-in seating, cabinets, work surfaces, and balcony-like observation areas inside the fixed shell. Furniture should be modeled as structural mass early so weight distribution stays visible in every drawing.
Module tasks
- Draw floor plates inside the fixed envelope.
- Reserve a central vertical core.
- Keep windows aligned with the existing side band.

# Phase 5: The Sun Deck as Civic Heart

The top access ring and recessed upper zone suggest a sun deck that is both private terrace and community interface. It can host gathering, solar maintenance paths, plant containers, meditation, stargazing, and graceful arrival from another AirShip.
Phase 5 technical focus: make the upper deck a real operating surface, not decorative space. The model shows a recessed top field and central opening; that geometry can organize solar service walkways, exterior seating, planter pockets, maintenance tie-downs, antenna masts, sensor housings, and weather-rated access panels while preserving the smooth body language of the craft.
Draw the deck in layers: drainage plane, walking surface, solar zones, access ring, hatch detail, handhold locations, lighting, data ports, and service panels. Keep the sun-deck specification practical: replaceable modules, clean cable routes, low-profile fixtures, and durable finishes. The result should feel like a terrace in the sky and function like an orderly roof plant room.
Interior planning tasks
- Map walking paths.
- Place furniture as removable modules.
- Preserve solar exposure.

# Phase 6: Interior Circulation

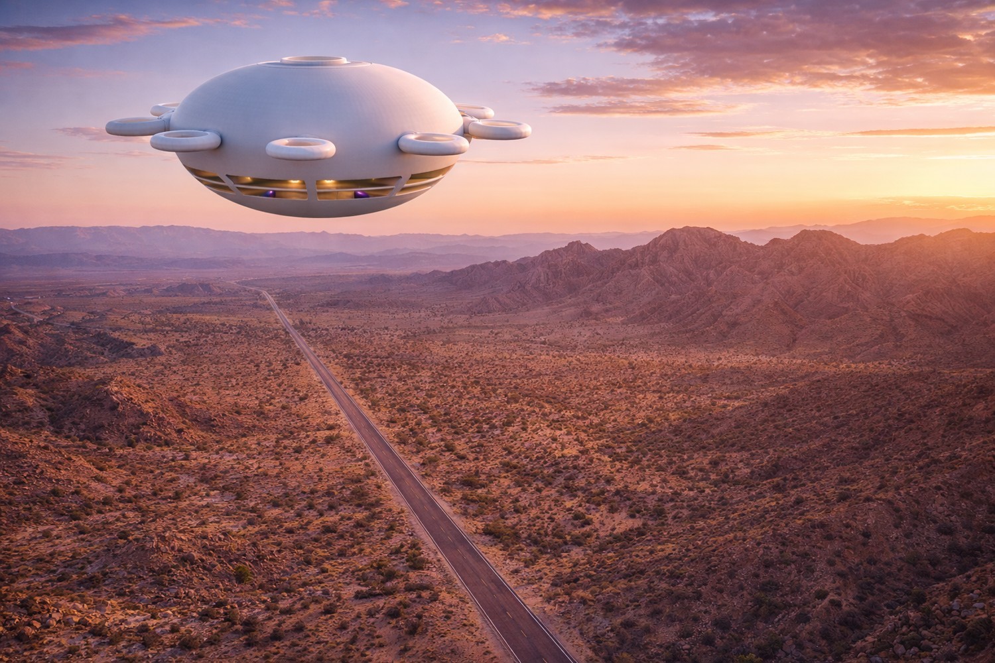
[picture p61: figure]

Interior planning view: the visible side band supports the two-floor home concept.
A luxury floating home needs circulation that feels intuitive. The central vertical core can connect the sun deck, upper floor, lower floor, and bottom access point. Around it, radial corridors can serve rooms without breaking the smooth exterior.
Phase 6 technical focus: the central cylindrical opening becomes the vertical address of the AirShip. Use it to coordinate stair geometry, daylight, ventilation paths, utility risers, emergency egress drawings, equipment access, and the relationship between upper deck, main living floor, lower living floor, and underside service exit. The white paper specifically imagines a spiral stair connecting the sun deck, main interior, and lower exit.
Model circulation at human scale with simple clearances: shoulder width, handrail reach, step rhythm, landing intervals, luggage movement, appliance delivery, and maintenance access. Create a full-size mockup of three stair segments, a hatch ring, and one curved wall section. This single mockup will reveal proportions, hand feel, lighting opportunities, and where the AirShip begins to feel like a home instead of a shell.
Deck development tasks
- Design a central stair/elevator concept.
- Keep service runs near the core.
- Use curved interior walls to echo the hull.

# Phase 7: Habitability and Comfort

The AirShip should feel serene. Comfort comes from daylight, acoustic softness, stable temperature, fresh air, generous storage, well-placed handholds, and rooms that can shift between travel, rest, and hosting.
Phase 7 technical focus: habitability depends on light, acoustics, temperature control, privacy, storage, and easy maintenance. Assign each cabin and shared room a comfort brief: seating count, sleeping count, expected noise level, daylight target, ventilation path, storage volume, power outlets, data ports, water access, and cleaning method. Luxury becomes measurable when each space is simple to occupy and simple to service.
Use the two-floor band for layered comfort. Put lively functions near shared view areas, quiet functions behind acoustic partitions, service equipment behind accessible panels, and storage where curved geometry would otherwise be wasted. The AirShip should read as advanced technology from outside and as an elegant apartment inside: warm surfaces, clear paths, hidden systems, and windows placed for long, cinematic horizons.
Circulation tasks
- Create a room-by-room comfort checklist.
- Mock up one cabin at full scale.
- Invite future residents to test layouts.

# Phase 8: Materials Palette

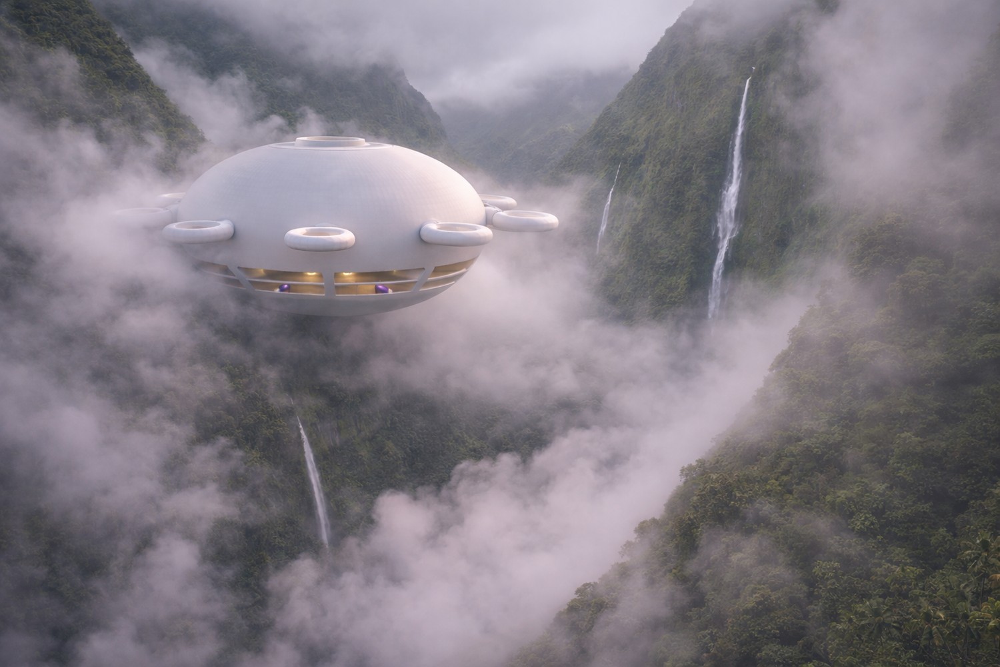
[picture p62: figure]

Circulation study: the central core organizes deck access, stairs, and service routes.
The source vision emphasizes abundant materials, carbon-based structures, 3D printing, recyclability, and solar-facing surfaces. The builder path is to create a material library ranked by strength, weight, repairability, printability, finish quality, and availability.
Phase 8 technical focus: organize materials by job, not by fashion. The source documents discuss carbon for carbon fiber and graphene concepts, nitrogen as an inert buffer, hydrogen produced from water by electrolysis, photovoltaics, hemp-based printable materials, and reusable or recyclable construction stock. Build a matrix with columns for structural role, mass, repairability, recyclability, printability, conductivity, finish quality, and supply chain maturity.
Run material trials as small coupons before committing to assemblies. Each coupon should record weight, stiffness, surface finish, joining method, thermal behavior, fastening behavior, and finish compatibility. For printable components, include nozzle size, layer height, infill, fiber orientation, post-processing, and part marking. The AirShip project improves fastest when every material choice creates data that another builder can repeat.
Comfort tasks
- Build sample coupons.
- Record mass and finish notes.
- Select materials through transparent review.

# Phase 9: Structural Rings and Frames

The exterior rings visible around the craft can be treated as functional modules: docking collars, propulsion housings, observation rings, service ports, or printable structural subassemblies. Their shared geometry makes them excellent candidates for early fabrication practice.
Phase 9 technical focus: the hull needs a disciplined hierarchy of rings, ribs, frames, panels, and service openings. Begin with major circular rings around the central core and perimeter belt, then connect them with radial frames that align to the wedge modules. This allows windows, cabins, buoyancy cells, utility runs, and exterior panels to reference the same structural grid instead of competing for space.
Produce three structural models: a clean visual model for form review, a simplified engineering model for loads and stiffness, and a fabrication model for joints and subassemblies. Label every frame by sector and elevation. Design joints so panels can be removed for inspection without disturbing finished interiors. The builder's goal is a beautiful shell that also behaves like a well-indexed kit of parts.
Material trials
- Model one perimeter ring in detail.
- Define its mechanical interface.
- Print display-scale and test-fit versions.

# Phase 10: Lift Architecture

Materials study: structure, skin, energy, and interiors are chosen as coordinated systems.
At a conceptual level, the AirShip is organized around buoyant volume, compartmentalized lift cells, trim management, and a structural shell that keeps the home form coherent. The builder team should turn this into a professionally modeled lift architecture that fits inside the fixed hull.
Phase 10 technical focus: lift planning begins with the buoyant volume budget. The white paper centers lighter-than-air operation and describes hydrogen as abundant and obtainable from water through electrolysis, with lift managed by gas handling and internal buoyancy architecture. In the guide, treat lift cells, service corridors, sensors, valves, tanks, and access panels as reserved volumes in the CAD model from the first planning pass.
Create a lift ledger that tracks estimated mass by subsystem: shell, frames, windows, interiors, power, storage, propulsion, water, equipment, residents, supplies, and margin. Pair it with a volume ledger for buoyancy spaces. The ledger should be updated after every design change, render, mockup, or part sample so the craft remains a coordinated flying home rather than a collection of attractive rooms.
Frame development tasks
- Create a volume map.
- Assign lift compartments to wedges.
- Review with aerostatics specialists.

# Phase 11: Solar Skin

The upper exterior is the natural solar field. Solar design should follow the existing curvature and recessed top geometry. The goal is a beautiful integrated skin, not a patchwork. Maintenance paths and replaceable panel zones can be planned as part of the surface system.
Phase 11 technical focus: the upper exterior is the natural solar field. The white paper imagines high-density photovoltaics over the exterior top apart from the sun deck, and the public plan emphasizes scaling with off-the-shelf components. Map solar coverage by curvature, shadow from the central ring, service walkways, module seams, cleaning access, cable routing, inverter placement, and replacement strategy.
Design solar skin as replaceable tiles rather than a single monolithic finish. Each tile should have a panel ID, electrical rating, connector type, mounting detail, seal detail, drainage path, inspection interval, and removal method. The recessed top geometry is ideal for an orderly photovoltaic garden: smooth from a distance, precise up close, and readable in the maintenance manual. Lift planning tasks
- Map high-sun surfaces.
- Define panel tiles.
- Route wiring through repeatable channels.

# Phase 12: Energy Storage and Distribution

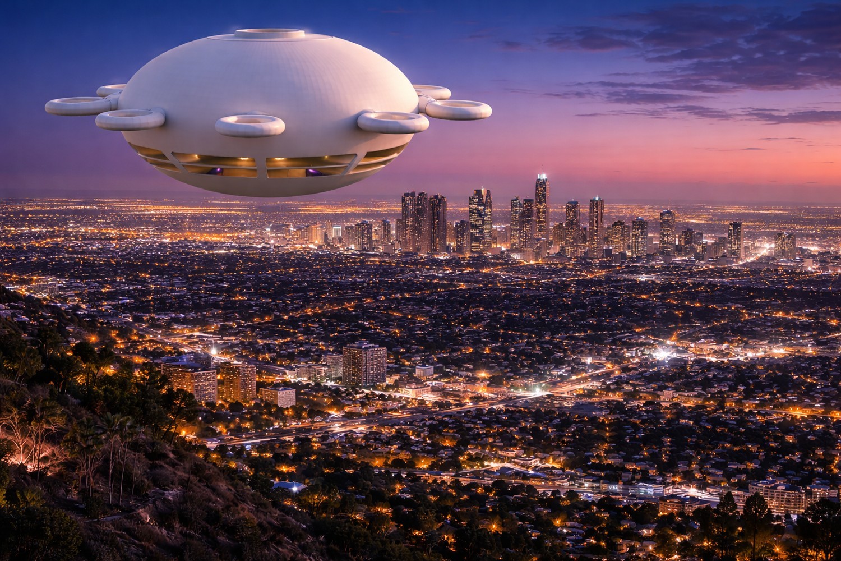
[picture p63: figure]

Lift study: buoyancy volume, mass ledgers, and service access develop together.
A floating home needs a calm electrical backbone: generation, storage, distribution, monitoring, and graceful prioritization. The energy system should be modular by wedge so that improvements can be introduced without redesigning the whole craft. Phase 12 technical focus: energy storage and distribution should be drawn as a house grid and a flight grid sharing a clear backbone. The source material points toward all-electric operation, graphene ultracapacitor ambitions, and modern storage improvements. Treat storage technology as a replaceable bay: define voltage architecture, cable trays, isolation points, thermal management, monitoring, access doors, and reserved expansion volume.
Build an energy one-line diagram early. Include solar input, charge controllers, storage modules, propulsion buses, cabin buses, lighting, galley loads, communications loads, pumps, sensors, computing, and shore or dock interface. Then create a physical routing drawing so cables, cooling, service panels, and furniture do not collide. A clean electrical architecture will make the AirShip easier to build, inspect, upgrade, and teach.
Solar skin tasks
- Draw a power one-line diagram.
- Create load categories.
- Prototype a bench-scale microgrid.

# Phase 13: Propulsion and Station Keeping

The eight perimeter modules can express balanced movement in every direction while reinforcing the circular identity. The practical design goal is quiet, efficient, symmetric control that lets the AirShip maneuver gracefully and hold position as a home. Phase 13 technical focus: propulsion in the source concept is arranged around perimeter thrusters, with discussion of efficient ducted or air-multiplier-like rings rather than traditional exposed propellers. The supplied model already expresses eight circular perimeter assemblies, so use them as the visual and functional basis for thrust, station keeping, low-speed maneuvering, and graceful hovering.
For each perimeter module, define thrust direction, duct diameter, motor bay, service hatch, cable route, sensor location, lighting, vibration isolation, and attachment interface. Create bench tests before flight prototypes: static thrust rig, acoustic reading, temperature run, power draw, duct insert variations, and control response. The rings should read as elegant architecture while behaving as precise maneuvering instruments.
Energy-system tasks
- Assign thrust modules to perimeter positions.
- Simulate symmetric control cases.
- Design removable service cartridges.

# Phase 14: Autonomy and Navigation

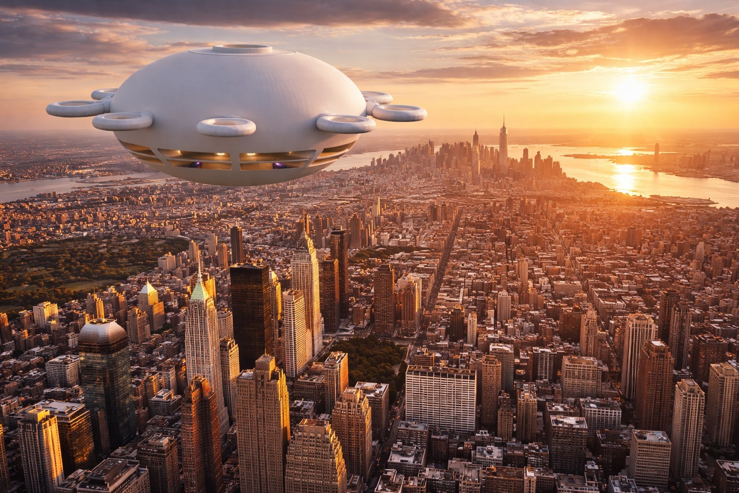
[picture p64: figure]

Energy study: solar skin, storage bays, and distribution routes are planned as one system.
The AirShip should be designed as a calm, sensor-rich home with assisted navigation. Autonomy begins with awareness: position, attitude, altitude, weather data, nearby craft, energy state, and route intent. The first prototypes can focus on observation and stable control.
Phase 14 technical focus: autonomy starts with sensing the world in three dimensions. The transcripts emphasize that automated navigation in open air can be simpler than urban road driving because the vehicle can model airspace, maintain separation, and avoid obstacles with modern sensors. Build the stack around positioning, altitude, inertial data, lidar or depth sensing, cameras, wind estimates, route planning, and human override interfaces.
Create a simulation workflow before building large hardware. The public plan names 3D navigation and blockchain route peer verification; translate that into recorded test routes, sensor logs, digital twin playback, route signatures, and reviewable autonomy decisions. Begin with a small model carrying a phone or sensor pack, then graduate to larger prototypes as the navigation data becomes repeatable.
Propulsion tasks
- Create a sensor map.
- Build a simulator dashboard.
- Log every test in open format.

# Phase 15: The Mesh Network Node

The AirShip can serve as a beautiful airborne communications node for a privacy-preserving community mesh. Practical builders should focus on lawful, cooperative, open protocols, local resilience, and service to residents, guests, educators, and neighboring craft.
Phase 15 technical focus: the AirShip can also be a network node. The white paper describes a peer-to-peer mesh using ultra-wideband radio concepts, encrypted traffic, frequency agility, blockchain incentives, and real-time data transfer. For a builder guide, convert this vision into hardware bays: radios, antennas, routing computers, storage modules, power conditioning, cooling, maintenance access, and externally documented interface standards.
The uploaded source also frames wireless design as a balance among data rate, distance, speed, number of users, and simultaneous streams. Use that tradeoff as the engineering worksheet for every network prototype. Record antenna placement, line-of-sight assumptions, link budget, packet loss, latency, power draw, enclosure temperature, and firmware version. Network design becomes practical when every flight produces measurable communications data.
Navigation tasks
- Prototype with permitted radios.
- Document network services.
- Create a resident-friendly connectivity panel.

# Phase 16: Water, Air, and Living Systems

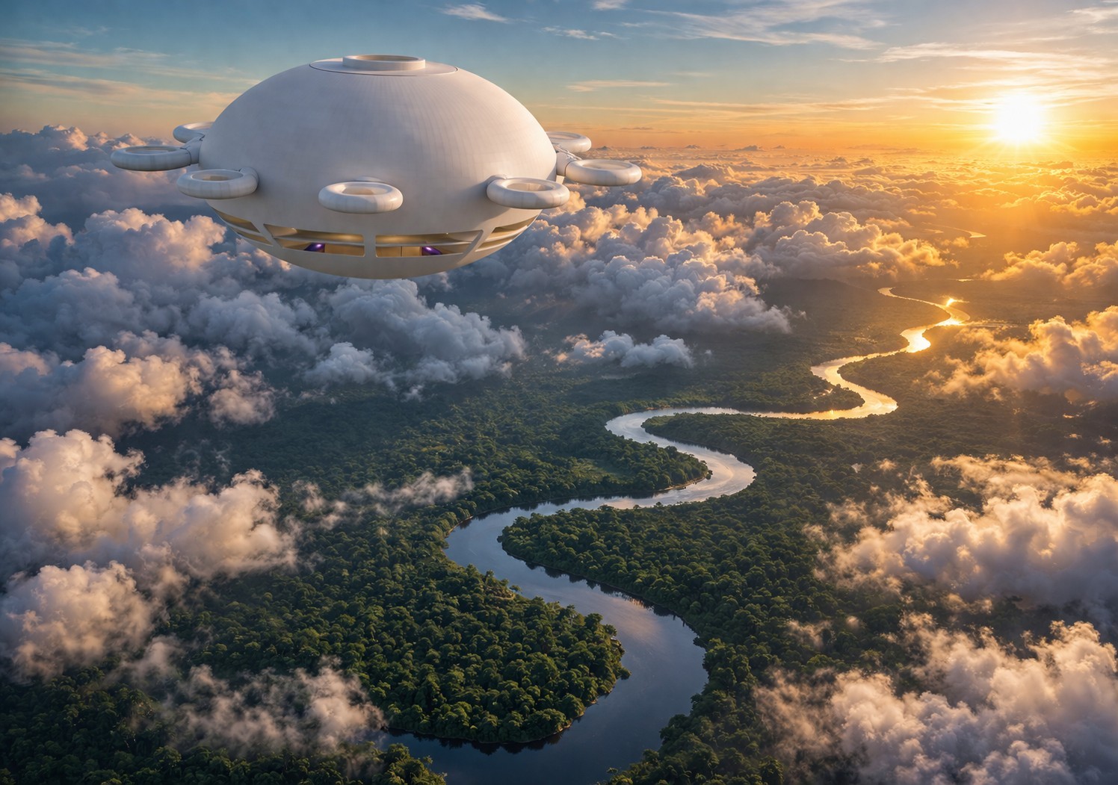
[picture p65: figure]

Autonomy study: sensing, route planning, and digital twin data support graceful navigation.
A floating home feels complete when essentials are abundant and elegant. Water capture, filtration, storage, efficient fixtures, fresh-air exchange, indoor planting, and maintenance access should be designed as visible signs of care.
Phase 16 technical focus: water, air, and living systems should be integrated like a small vessel and a high-end residence. Reserve service volume for potable water, filtration, pumps, greywater treatment, humidity control, ventilation, thermal recovery, air-quality sensors, and maintenance drains. The white paper's abundance language includes water, sewage treatment, electricity, and food, so each utility should have a visible pathway from source to use to recovery.
Create a utilities board before building rooms. Mount representative pumps, valves, tanks, filters, sensors, wiring, and controls on a test panel at human scale. Label every line and measure power draw, noise, service time, and replacement clearance. Then fold the tested layout back into the curved interior so everyday residents see beautiful rooms while maintainers see an intelligible machine. Mesh-node tasks
- Create a resource loop diagram.
- Separate potable, grey, and garden water paths.
- Design systems as accessible furniture-like modules.

# Phase 17: Food and Garden Modules

OpenAirShips imagines food abundance alongside mobility. The AirShip home can begin with compact gardens: herbs, greens, seed libraries, mushroom drawers, microgreens, and balcony planters on the sun deck. Larger fleet members can host farms and nurseries.
Phase 17 technical focus: food systems can begin small and become a signature capability. The source plan imagines AirShip FarmBots, permaculture food forests, hydroponic hemp farms, and local production of hemp-based filament. Inside the luxury home, start with compact grow cabinets, herb walls, seed storage, compost experiments, and a small nursery station connected to the water and lighting plan.
For community-scale work, separate residential gardens from production modules. A residential module is quiet, clean, and beautiful. A production module is optimized for tray access, nutrient delivery, robotics, harvesting, drying, seed saving, and fiber processing. Document both. The AirShip becomes more useful when it can host a dinner, teach horticulture, and support material production with the same design language.
Living-system tasks
- Design a galley garden wall.
- Create seed storage.
- Plan fleet-scale farm variants.

# Phase 18: Waste as Resource

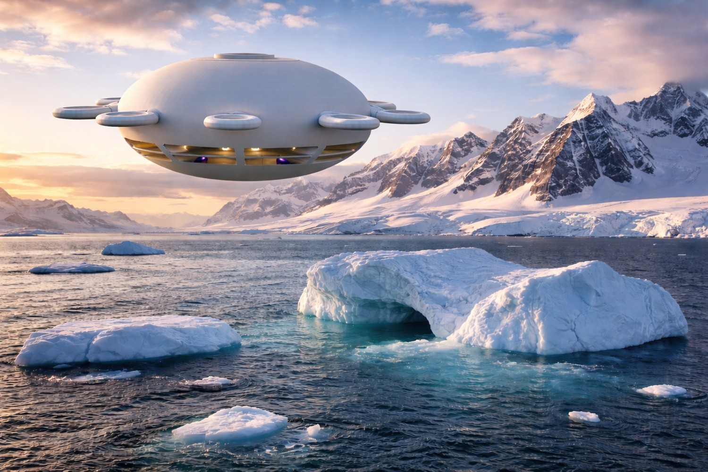
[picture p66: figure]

Living systems study: water, air, power, and comfort are integrated into the home.
A practical society treats outputs as inputs. Organic matter, packaging, worn parts, wash water, and fabrication scraps can be sorted into loops for composting, reuse, repair, recycling, and design improvement.
Phase 18 technical focus: treat every output stream as a design input. Track organic waste, greywater, packaging, print scraps, worn panels, filters, and maintenance parts. The white paper calls for reusable and recyclable materials so outdated designs can be melted down or repurposed; that idea becomes a workshop protocol when parts are labeled by material, revision, mass, and next use.
Build a circular-materials station into the workshop plan: sort bins, wash area, shredder or grinder space, filament testing, sample storage, and a digital inventory. Every failed prototype should still yield geometry lessons, mass data, material behavior, and reusable feedstock. This keeps the project lively and precise: nothing disappears into vague waste, and every experiment improves the next component.
Garden module tasks
- Create labeled resource stations.
- Design removable collection drawers.
- Track material return rates.

# Phase 19: 3D Printing for Replication

The source vision places 3D printing at the center of growth. The practical starting point is a parts library for non-critical components: interior brackets, covers, handles, planters, ducts, templates, model sections, and educational kits.
Phase 19 technical focus: 3D printing is not merely a way to make parts; in the OpenAirShips vision it is the replication engine. The white paper imagines AirShip printers moving hot ends accurately through space, multiple printer nodes collaborating, and different materials being deposited together. Start with conventional printers for parts, then document the path toward larger robotic fabrication.
Create a print standard for every component: file name, material, layer orientation, infill, reinforcement, surface finish, tolerance, post-processing, test fit, part ID, and replacement interval. For multi-material ambitions, define which elements carry structure, conductivity, sealing, insulation, and finish. A printed AirShip becomes plausible when each part is boringly well documented and delightfully easy to improve.
Resource-loop tasks
- Start with small printed parts.
- Attach QR codes to part histories.
- Maintain parametric source files.

# Phase 20: The AirShip Workshop

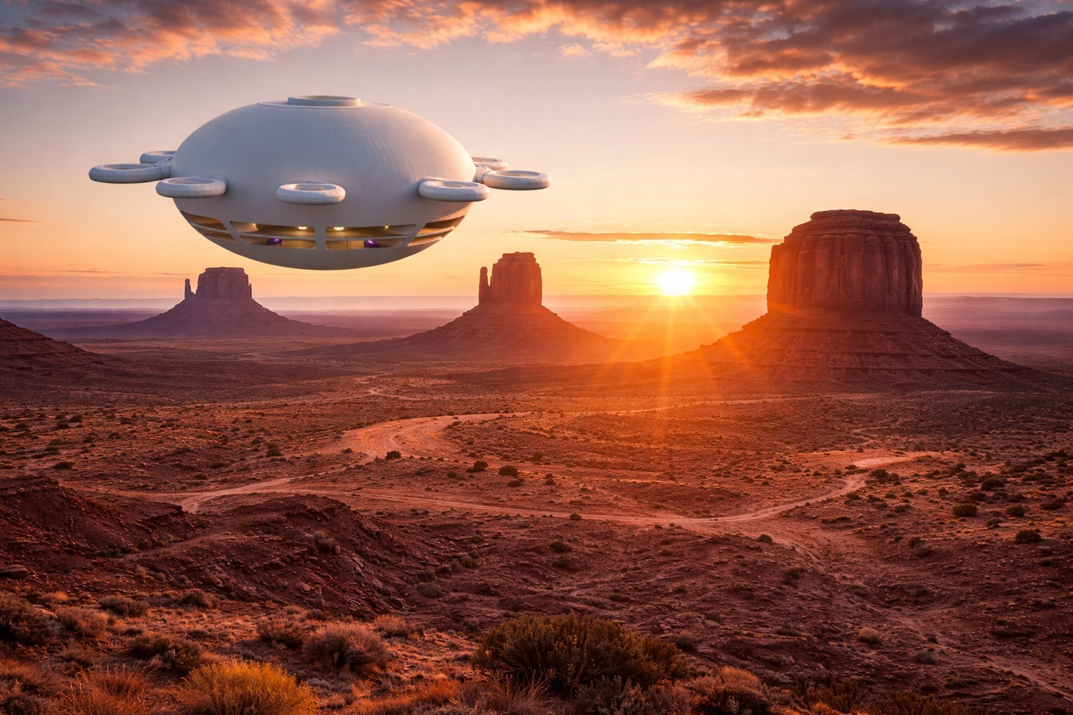
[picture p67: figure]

Resource loop study: materials, print scraps, water, and food systems feed future work.
Every serious build needs a workshop that feels like the future it serves: clean benches, model wall, print farm, materials library, electronics bench, documentation station, and a hospitality area where newcomers can understand the dream in minutes.
Phase 20 technical focus: the workshop is the first physical AirShip system. It should contain CAD stations, printer bays, material storage, assembly benches, coupon testing, electronics benches, photo documentation, packing, and a clean review table for finished parts. The OpenAirShips get-involved page names aeronautical, radio, materials, electrical, blockchain, Linux, encryption, video, and 3D-printing specialists; the room should welcome all of them.
Arrange the workshop around flow: idea, drawing, small print, test coupon, subsystem mockup, review, revision, publication. Put cameras and measurement tools where they are used, not hidden in drawers. A beautiful workshop culture produces beautiful craft because the same care given to a surface finish is given to filenames, labels, checklists, and the way people hand work to each other.
Replication tasks
- Create zones for CAD, print, assemble, test, document.
- Display the reference model prominently.
- Host weekly open studio hours.

# Phase 21: Prototype Ladder

Move from small to large with grace. The ladder can include desk model, display model, module mockup, interior cabin mockup, sensor gondola, tethered demonstrator, autonomous demonstrator, one-room hull mockup, and full home integration model. Phase 21 technical focus: prototype in a ladder. The transcript proposes beginning with very small craft, even a test model capable of carrying a phone for remote presence, before moving toward rideable scale. That ladder can be formalized as desktop geometry, buoyancy cell coupon, perimeter duct test, sensor gondola, room mockup, small autonomous demonstrator, one-sector module, and full-scale interior segment.
Each rung should answer one question cleanly. Does the duct make enough thrust? Does the window band feel spacious? Can the stair core be entered comfortably? Does a sensor package hold altitude? Does a printed bracket meet the interface drawing? Do not ask one prototype to prove everything. Let each object be a clear sentence in the larger engineering story.
Workshop setup tasks
- Define success for each rung.
- Limit each prototype to one main question.
- Publish lessons after each build.

# Phase 22: Digital Twin

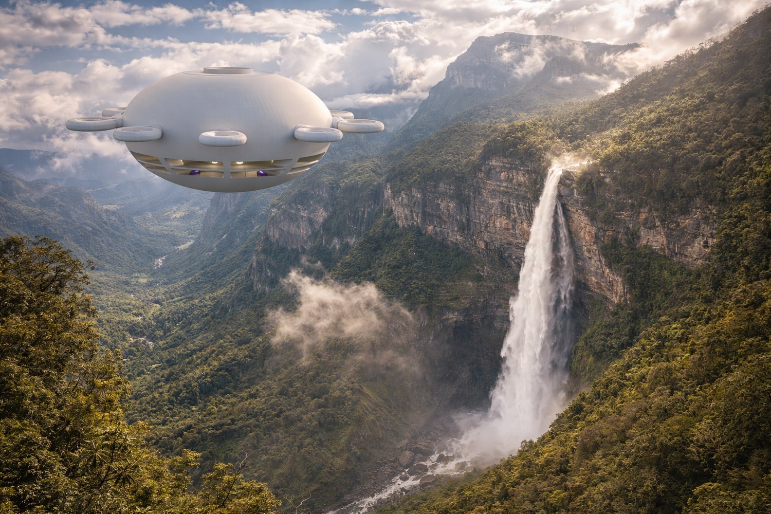
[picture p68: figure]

Workshop study: fabrication, testing, photography, and publication share one space.
A digital twin lets the AirShip evolve as a coordinated system. It can combine CAD, mass estimates, energy models, interior layouts, sensor data, maintenance logs, and community feedback into one living model.
Phase 22 technical focus: the digital twin is the living memory of the build. It should hold geometry, mass, components, wiring, plumbing, energy, sensor data, prototype results, maintenance records, and render-ready scenes. Because OpenAirShips emphasizes open-source iteration, the twin should be legible to new contributors: clean layers, obvious names, linked drawings, and change notes written for humans.
Use the digital twin to compare imagined performance with measured performance. After every print, weigh the part and update the mass ledger. After every bench test, attach power, heat, noise, and fit notes. After every render, record which geometry version produced it. Over time, the twin becomes more than a model; it becomes the shared operating language of the project.
Prototype tasks
- Choose a shared repository.
- Connect CAD views to requirements.
- Update the twin after every test.

# Phase 23: Review Rituals

The project needs rituals that keep optimism organized. A weekly review can celebrate progress, compare prototypes, update requirements, invite critique as contribution, and keep decisions aligned with the reference atlas.
Phase 23 technical focus: reviews should be structured enough to improve quality and light enough to invite participation. Use four review modes: geometry review, systems review, fabrication review, and story review. Geometry checks the reference body. Systems checks power, lift, water, network, and controls. Fabrication checks whether parts can be made. Story checks whether drawings, images, and text help new builders understand the work.
Give every review a visible output: accepted drawing, open issue, changed dimension, new test, updated render, or clearer paragraph. The best review ritual makes decisions traceable without becoming theatrical. Publish short notes, mark owners, and close the loop. A contributor should be able to join months later and understand not only what was decided, but why the decision made the AirShip easier to build.
Digital twin tasks
- Open with the vision.
- Review geometry changes first.
- Close with published next steps.

# Phase 24: Documentation as Infrastructure

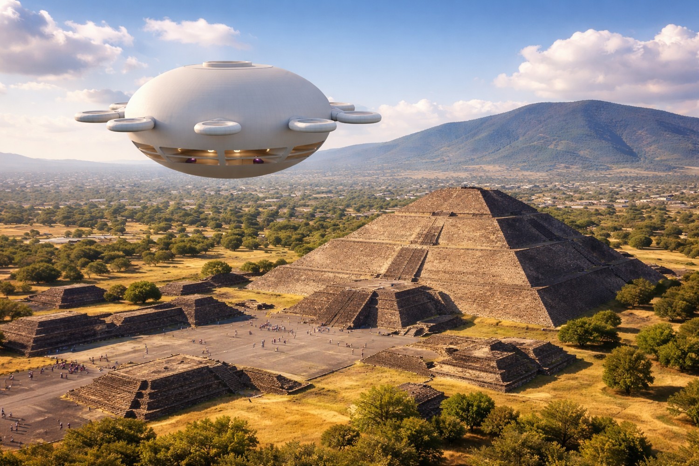
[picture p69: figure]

Digital twin study: CAD, test data, and documentation remain synchronized.
Documentation is not paperwork; it is how the AirShip replicates. Every part, test, decision, material, and room concept should have a page that another builder can follow. Good documentation turns one workshop into a global classroom.
Phase 24 technical focus: documentation is infrastructure. The white paper depends on open replication, and the public site points people toward the plan, white paper, GitHub, and community discussion. Build the document system as if it were a subsystem of the craft: versioned folders, part numbers, diagrams, photos, test reports, meeting notes, source snapshots, contributor credits, and publication checklists.
Use a documentation template for each part and each subsystem. Include purpose, drawing, material, mass, interface, tool requirements, build steps, inspection points, revision history, and next experiments. Good documentation lets a builder in another city reproduce a bracket, improve a duct, translate a page, or spot a better route for a wire without needing to ask for private context.
Review tasks
- Use templates.
- Photograph every assembly.
- Write for a capable newcomer.

# Phase 25: Open Source Governance

A strong build community needs fair ways to decide. Governance can include proposals, design review boards, resident councils, contributor credits, transparent budgets, and elected maintainers for core modules.
Phase 25 technical focus: open-source governance should make contribution simple and excellence visible. The OpenAirShips open-source page describes commitment to releasing designs and software for public improvement, and the GitHub repository provides a home for shared assets. Define contribution types: CAD, code, renders, tests, writing, outreach, materials research, supplier notes, and workshop lessons.
Create a lightweight governance map: maintainers, reviewers, release managers, issue labels, file standards, design proposals, accepted changes, and archived experiments. Pair freedom with clarity. A contributor should know where to submit a part, how to name it, what evidence supports it, who reviews it, how it becomes official, and where its story appears in the next public release. Documentation tasks
- Create proposal formats.
- Publish voting records.
- Reward maintainers and teachers.

# Phase 26: The Contribution Economy

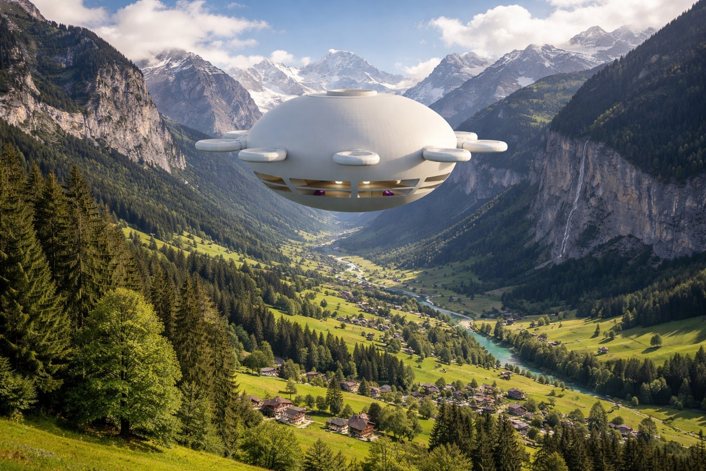
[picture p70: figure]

Documentation study: drawings, photos, revision notes, and part records become infrastructure.
The source materials imagine rewards for useful contributions: transport, housing, printing, food, education, media, governance, storage, and network services. The practical version can start with credits, reputation, grants, bounties, and shared ownership pools.
Phase 26 technical focus: the contribution economy turns useful work into recognized value. The white paper lists many contribution categories: network data transfer, storage, node deployment, development, mapping, transportation, housing, 3D printing, water, electricity, food, seeds, education, governance proposals, voting, media, and exchange. Treat this list as an early service catalog for the AirShip civilization.
Build a ledger prototype before building a token. Record tasks, deliverables, reviewers, evidence, time, materials, and resulting benefit. A 3D printed bracket, a hydroponic tray, a mesh relay test, and a training video can all be logged in the same structure. This keeps the economy grounded in real outputs, real learning, and visible progress rather than abstract enthusiasm.
Governance tasks
- List contribution categories.
- Define evidence of work.
- Create a public gratitude ledger.

# Phase 27: A Floating Neighborhood

One AirShip is a home. Many AirShips become a neighborhood. The circular form encourages docking clusters, shared sun decks, classroom gatherings, repair exchanges, garden swaps, music nights, and cooperative routing.
Phase 27 technical focus: a floating neighborhood needs spatial rules. Define docking distance, communication protocol, shared service windows, quiet hours, resource exchange points, guest arrival paths, emergency meeting points, and common cultural practices for meals, workshops, education, and maintenance. The AirShip is a home, but a fleet becomes a living district with its own geometry and rhythm.
Draw neighborhood diagrams at several scales: two AirShips visiting, eight AirShips in a circle, a workshop cluster, a garden cluster, a river or bay gathering, and an overland travel formation. Include data links, lighting, water exchange, cargo transfer, social spaces, and service access. A good fleet plan feels like a marina, a campus, and a constellation all at once. Contribution-economy tasks
- Design gathering protocols.
- Create shared calendars.
- Map services across the fleet.

# Phase 28: Luxury Without Waste


Contribution study: useful work is recorded, reviewed, credited, and improved.
Luxury in this society is beauty, time, health, movement, learning, and belonging. Interiors can use durable finishes, modular furniture, natural textures, excellent lighting, and quiet systems that make the home feel generous without burden.
Phase 28 technical focus: luxury without waste is a specification. Replace vague luxury with measurable qualities: excellent view lines, quiet sleeping rooms, durable surfaces, thoughtful storage, low-maintenance fixtures, warm lighting, efficient appliances, repairable furniture, and systems hidden behind elegant access panels. The craft should feel rich because every square meter performs beautifully.
Design interior modules as built-in furniture rather than loose objects fighting the curve. Window benches can hold storage. Curved walls can hide ducts. Stair landings can become reading shelves. Galley cabinets can double as structural partitions. The shell geometry is not a limitation; it is the design language that makes the home distinct from apartments, yachts, aircraft, and recreational vehicles.
Neighborhood tasks
- Design multi-use furniture.
- Choose repairable finishes.
- Use lighting scenes for daily rhythms.

# Phase 29: Education Aboard

Each AirShip can be a school. Residents and guests can learn navigation, gardening, electronics, CAD, cooking, music, languages, repair, governance, and stewardship. Education makes the fleet self-renewing.
Phase 29 technical focus: education aboard should be hands-on and modular. Create lessons around buoyancy, solar power, CAD, 3D printing, water systems, mesh networking, gardening, open-source licensing, rendering, storytelling, and community operations. Each lesson should connect one visible feature of the AirShip to one skill a builder can practice immediately.
Turn every subsystem into a teaching station. A transparent utility panel can explain water flow. A removable solar tile can teach wiring and maintenance. A printed bracket can teach materials and tolerances. A mesh radio bay can teach decentralized networking. A living classroom helps the project recruit skilled contributors because newcomers learn by touching real parts. Luxury-detail tasks
- Build a learning wall.
- Host skill circles.
- Create youth-friendly model kits.

# Phase 30: Health and Wellbeing


Luxury study: built-in furniture, warm light, views, and service access shape the interior.
The AirShip home should support sleep, movement, sunlight, fresh meals, quiet work, and community connection. Health is designed through routines as much as hardware: morning deck time, shared meals, creative work, garden care, and evening observation.
Phase 30 technical focus: health and wellbeing are layout decisions. Prioritize daylight, clean air, low noise, comfortable sleeping, gentle circulation, access to plants, places for exercise, social dining, quiet work, and views of land, water, and sky. The AirShip should allow a household to live slowly while the craft moves elegantly through space.
Create a wellbeing schedule for the design: morning light at breakfast, shaded work zones at midday, quiet evening cabins, night lighting that preserves calm, and fresh-air paths that do not disturb sleeping areas. Measure comfort with mockups and occupant notes. A home in the air succeeds when residents forget the complexity of the machine and remember the grace of the day. Education tasks
- Plan wellness zones.
- Use circadian lighting.
- Create daily care rituals.

# Phase 31: Art Direction

Reference OpenAirShips.com for additional art ideas, model lineage, and blueprint inspiration. The visual language should be optimistic: white hull, soft solar surfaces, warm interiors, luminous windows, green decks, and radial geometry.
Phase 31 technical focus: art direction must protect the recognizable model while improving finish, texture, color, light, and storytelling. Use the supplied renders as environment studies: coastline, clouds, desert, jungle, city, snow, valley, and water. The AirShip should keep its circular body, central top opening, perimeter rings, and two-floor side band while materials and lighting create variety.
Create an art bible with render angles, lens choices, daylight palettes, surface finishes, interior warmth, window glow, panel pattern, scale cues, and human presence. Include OpenAirShips.com as the reference hub for further art ideas, public assets, and technical context. The goal is a visual identity that makes the craft instantly recognizable across every image, blueprint, animation, and poster.
Wellbeing tasks
- Create a mood board.
- Render the same shape in multiple environments.
- Maintain visual continuity across all renders.

# Phase 32: Blueprint Package


Health study: daylight, quiet rooms, clean air, and plants make the craft livable.
The blueprint package should be a growing set of views: locked exterior, plan, section, module, floor layout, access core, solar map, power map, network map, water loop, interior elevations, and fleet docking diagrams.
Phase 32 technical focus: the blueprint package should contain enough information to guide a serious builder from concept to prototype. Include general arrangement, top plan, side elevations, underside view, section cuts, wedge module drawing, central core drawing, floor layouts, utilities diagrams, energy one-line, mesh-node diagram, propulsion module diagram, materials matrix, and prototype ladder.
Make every blueprint page earn its place. Add scale bars, orientation markers, part labels, revision number, author, source file, and inspection notes. Separate presentation drawings from fabrication drawings. A presentation page sells the vision; a fabrication page tells a builder what to make, where it fits, how it connects, and what evidence proves it works.
Art-direction tasks
- Start with reference views.
- Add dimensions only after expert review.
- Version every sheet.

# Phase 33: Full-Scale Interior Mockup

Before building a full craft, build rooms. A full-scale slice can test ceiling heights, window placement, stairs, furniture, storage, lighting, mechanical access, and emotional comfort inside the reference envelope.
Phase 33 technical focus: a full-scale interior mockup is the bridge between beautiful renders and livable architecture. Build one curved wall bay, one window band section, one floor transition, one storage module, one service panel, and one stair segment. Use inexpensive materials first, but match dimensions, sight lines, handle positions, lighting levels, and seating heights.
Run the mockup like a small apartment. Prepare a meal, sit with a laptop, store luggage, open panels, move through the stair, and host a conversation. Photograph every posture and every awkward reach. Then revise the CAD. This is where luxury becomes physical: a hand lands naturally, a cabinet opens cleanly, and a view frames the horizon.
Blueprint tasks
- Mock up one radial slice.
- Invite walkthroughs.
- Record resident feedback.

# Phase 34: Model-Based Fabrication


Blueprint study: controlled drawings translate the model into build packets.
Fabrication should flow from the digital twin to jigs, templates, molds, printed parts, and assembly instructions. A builder can begin with display-scale models, then move to full-scale interior components and non-flight exterior panels.
Phase 34 technical focus: model-based fabrication means the model is the source of truth. Parts should be generated from the controlled CAD atlas, exported in standard formats, labeled by revision, and checked against the physical part after fabrication. When the same geometry produces drawings, renders, prints, and inspection templates, the build becomes faster and more trustworthy.
Define fabrication packets for hull panels, ring modules, brackets, ducts, interior modules, and utility boards. Each packet should include model file, drawing PDF, print or fabrication settings, material, expected mass, tolerance, surface finish, assembly sequence, and photo checklist. A builder should be able to open one packet and know exactly how that part contributes to the whole craft.
Mockup tasks
- Create printable templates.
- Mark parts with orientation.
- Use assembly photos in the build manual.

# Phase 35: Systems Integration Day

Choose regular integration days where teams connect their work: power with interiors, water with structure, controls with propulsion, solar with maintenance access, network with resident interface. Integration turns separate inventions into a home. Phase 35 technical focus: systems integration day is a rehearsal for the complete AirShip. Bring power, controls, sensors, water, lighting, communications, and mechanical assemblies together on benches and mockups before they enter the hull. Integration should expose interface needs: connectors, access doors, labeling, mounting plates, software versions, calibration steps, and spare parts.
Write an integration script with start state, steps, expected readings, photos to capture, and sign-off criteria. Power the cabin lights, run a pump, boot the mesh node, spin a ducted fan on the bench, log sensor data, and update the digital twin. The day should end with fewer mysteries and a clearer bill of materials.
Fabrication tasks
- Bring physical parts to the same table.
- Review interfaces.
- Publish updated diagrams.

# Phase 36: Community Workshop Curriculum


Fabrication study: model-based parts move from CAD to printed components.
A practical project invites people in. Build a curriculum that teaches the AirShip idea in one afternoon: model tour, modular wedges, solar skin, garden loop, mesh node, interior mockup, and contribution opportunities.
Phase 36 technical focus: the community workshop curriculum should be a builder pathway. Start with AirShip geometry and source history, then teach CAD basics, model naming, 3D printing, material coupons, solar tiles, simple circuits, mesh networking, interior mockups, rendering, documentation, and open-source contribution. Each class should produce a visible artifact for the shared library.
Organize workshops by skill level. Beginners label model features and assemble simple parts. Intermediate builders test brackets, document materials, and improve diagrams. Advanced contributors work on simulations, controls, radio hardware, energy systems, and structural analysis. The curriculum turns spectators into contributors by giving everyone a practical door into the project.
Integration tasks
- Create slides and handouts.
- Offer beginner tasks.
- Record sessions for remote builders.

# Phase 37: Funding the Dream

Funding should match the ethos: transparent, milestone-based, community-owned where possible, and tied to visible prototypes. Supporters should see exactly what their contribution creates, from model refinement to room mockups to sensor benches. Phase 37 technical focus: funding should be tied to milestones that produce durable assets. Fund a CAD cleanup, a model atlas, a perimeter duct prototype, a solar tile mockup, a full-scale window bay, a mesh-node bench test, a material coupon library, a documentary short, or a public blueprint release. Each milestone should leave behind files, photos, data, and a reusable lesson. Create a funding board with budget, supplier list, owner, deliverable, publication date, and follow-up test. The OpenAirShips history includes an early crowdfunding attempt; the next version can make support tangible by showing exactly what a contribution builds. People support a dream more easily when the next artifact is specific, beautiful, and useful.
Curriculum tasks
- Publish milestone budgets.
- Show prototype photos.
- Offer contributor credits and open access.

# Phase 38: Partnerships


Fleet study: homes, workshops, gardens, relays, and classrooms share the same design family.
The AirShip needs friends: universities, makerspaces, aeronautical engineers, materials labs, solar designers, interior architects, permaculture teachers, open-source communities, and artists. Partnerships turn a single dream into a civilization-scale craft tradition.
Phase 38 technical focus: partnerships should map to missing capabilities. The public site lists specialist needs including aeronautical engineers, radio hardware engineers, materials scientists, electrical engineers, blockchain coders, Linux programmers, encryption experts, 3D printing experts, video production, and airspace consultants. Use that list as a practical recruiting map for labs, makerspaces, universities, suppliers, and independent builders.
Prepare partner packets rather than general pitches. A materials lab gets coupon requirements. A radio specialist gets mesh-node questions. A design school gets interior mockups and renders. A makerspace gets printable brackets. An electrical engineer gets the energy one-line. Clear packets respect expert time and turn outside interest into useful, credited contributions.
Funding tasks
- Create a partner map.
- Write invitation letters.
- Define shared deliverables.

# Phase 39: Beautiful Interfaces

Residents should not need to understand every system to live well. The interface can show energy, water, air, garden, route, community messages, maintenance prompts, and learning opportunities in a warm, simple dashboard.
Phase 39 technical focus: interfaces make advanced systems livable. Residents should see calm dashboards for power, water, air quality, route, network status, maintenance reminders, cabin comfort, and community exchange. Technicians should see deeper diagnostic pages with sensor readings, logs, firmware versions, connector maps, and test routines. The same system can be graceful for residents and exact for builders.
Prototype interfaces with paper screens first, then clickable mockups, then live data from bench systems. Avoid visual clutter. Use clear states, large labels, plain language, and beautiful status views. The interface should feel like the instrument panel of a floating home, not a laboratory console, while still giving engineers the detail needed to keep improving every subsystem.
Partnership tasks
- Prototype a wall display.
- Use plain language.
- Add celebration signals for abundance.

# Phase 40: Fleet Services


Research study: primary sources, public pages, and test data stay organized for future builders.
A society of AirShips can specialize. Some craft can be homes, some farms, some clinics, some classrooms, some fabrication shops, some guest houses, some theaters, some relay nodes, and some repair docks.
Phase 40 technical focus: fleet services turn individual homes into a network of capabilities. Define service roles: housing, guest hospitality, mobile workshop, garden module, print shop, water processing, energy support, communications relay, classroom, studio, clinic room, and cargo bay. The white paper's contribution list already contains many of these functions; the builder guide should assign spatial and technical requirements to each one.
Make fleet services modular. A workshop AirShip needs tool storage, benches, dust management, printers, parts library, and extra power. A garden AirShip needs trays, water, nutrients, lighting, harvesting, and seed storage. A relay AirShip needs antennas, routers, energy reserves, cooling, and diagnostics. Shared geometry lets different service craft feel like members of the same family.
Interface tasks
- Define service archetypes.
- Keep the common hull language.
- Create exchange protocols.

# Phase 41: Docking and Hospitality

The perimeter rings suggest social architecture. They can become docking symbols, guest entry points, transfer ports, observation loops, or service nodes. Design them as places of welcome and graceful exchange.
Phase 41 technical focus: docking and hospitality are where engineering meets manners. Define how people arrive, where they step, what they hold, where luggage goes, how hosts greet guests, how service crews access panels, and how two craft exchange supplies. The white paper imagines traversal between AirShips through top and bottom access, so docking drawings should include vertical and horizontal arrival scenarios.
Build a hospitality storyboard. Show arrival lights, hatch opening, stair sequence, greeting area, shoe and bag storage, guest orientation, meal service, sleeping arrangements, and departure. Then make technical drawings for handholds, thresholds, lighting, signage, intercom, docking guides, and cargo handoff. A great AirShip makes arrival feel effortless because the choreography has been designed.
Fleet-service tasks
- Map guest arrival flows.
- Design signage.
- Create shared etiquette cards.

# Phase 42: Stewardship Governance

A flourishing society is built through daily habits: open books, respectful meetings, shared learning, restorative conflict practices, resident councils, child-friendly participation, elder respect, and contribution paths for many abilities.
Phase 42 technical focus: stewardship governance keeps the project coherent as it grows. Define who maintains the master model, who approves releases, who reviews tests, who credits contributors, who archives old ideas, who publishes public updates, and who keeps the workshop safe, orderly, and welcoming. Governance should be visible in templates, calendars, labels, and release notes.
Create three recurring documents: the monthly release note, the open issues board, and the build journal digest. The release note shows what changed. The issue board shows what needs help. The digest tells the story of the work in plain language. Together they let the community scale without losing the practical beauty of the original craft.
Docking tasks
- Write a community charter.
- Create rotating steward roles.
- Celebrate useful work publicly.

# Sources and Continuing Research

Core source documents used for this guide include the supplied OpenAirShips white paper, the supplied AirShip transcripts, and the four supplied model views. The public OpenAirShips.com page describes the goal as low-cost housing and transportation and the plan as small, modular, open-source, 3D-printable autonomous AirShips that scale using off-the-shelf components. Recommended continuing research streams: OpenAirShips.com for project art, files, and community direction; the OpenAirShips GitHub for project repository material; public 3D model repositories for visual study; airship history archives for precedent; current lighter-than-air research for state-of-the-art design language; and professional aeronautical, materials, electrical, and habitat-design references for engineering development.
Keep source notes positive and useful. The goal of research is not to copy the past, but to gather enough wisdom to build a beautiful future with confidence and clarity.
Stewardship tasks
- Save source snapshots with dates.
- Credit every contributor.
- Update the blueprint package whenever a source improves the build.
Source foundation: supplied OpenAirShips white paper and video transcripts, supplied model screenshots and wireframes, and OpenAirShips.com for additional art ideas, blueprint context, and continuing technical research.


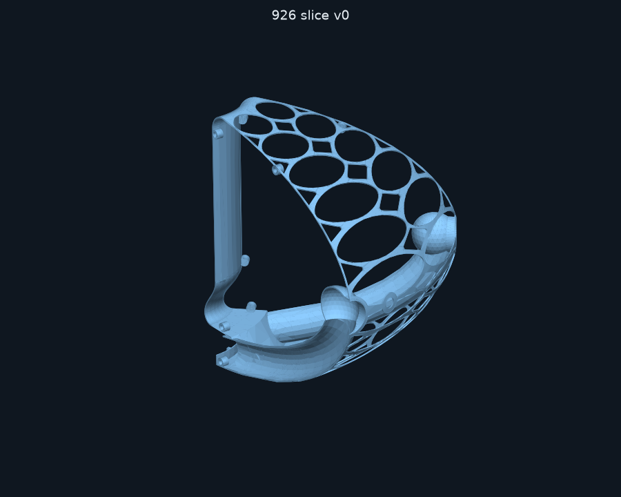
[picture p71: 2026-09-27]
web/assets/images/build/slice.png

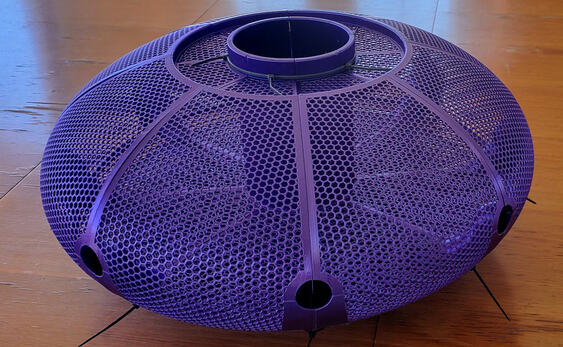
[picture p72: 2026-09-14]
web/assets/images/plan/airship-print-2024.jpg

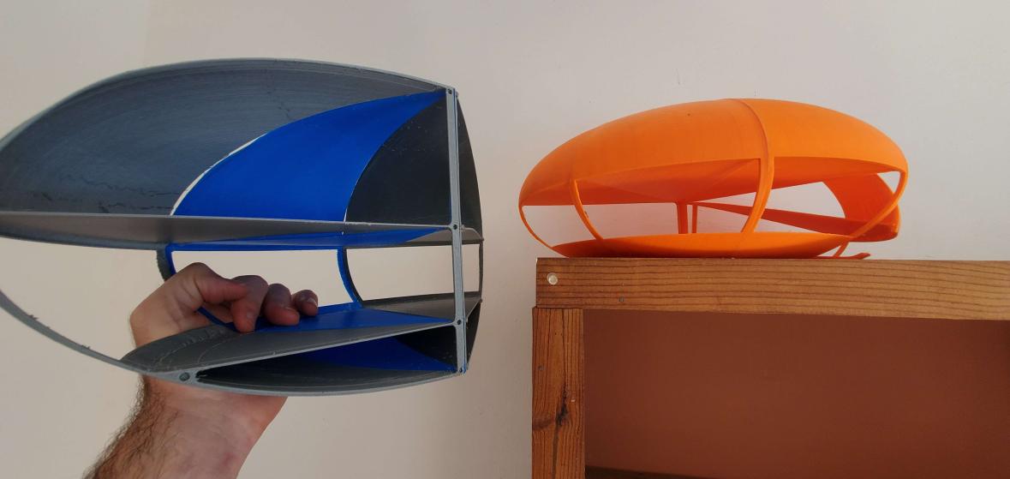
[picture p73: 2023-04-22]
ExistingPrintedPrototypeSansDucts.jpg

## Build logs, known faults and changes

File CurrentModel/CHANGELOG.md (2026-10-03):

# Changelog: OpenAirShips buildable model (1026, formerly 926)

## 1026 v0.2.1: flush fan housing and lighter keel (October 2026)

The model is renamed **1026** for October 2026, following the project's month-year naming (the 926 files are in `OldFiles/PrintFiles/926` and `OldFiles/CAD/926`).

- **Flush duct mouths.** Each thrust duct now runs straight on from the fan housing with no step, inside or out.
  - The ducts hug the hull curve at a constant depth all the way from their mouths, so their bottoms continue the housing floor (the keel skin).
  - The housing ceiling stays over the impeller's blade tips, then eases down to meet the ducts' tops at the mouths.
  - The housing's outer wall stands just past the mouths (r = 60.5 mm instead of sloping out to r = 80). Where it meets a duct, the duct wall is trimmed to the housing's exact inside shape, so there's no lip inside and no gap outside.
  - A new leak test checks that the inner half of every wall round the joint is solid. It found the gap in the first attempt and passes on every slice now.
- **Ovals and diamonds right up to the housing.** A bug placed the first ring of ribs 3 mm *higher* than the housing's edge. On the nearly flat keel that's about 13 mm further out, which left a band of plain skin. The first rib now sits just outside the housing wall, so the only solid keel is the housing floor between the hatch ring and that wall.
- **Big cells near the axis (double Kobra):** the junction windows of the first row are now laid out on the unrolled skin instead of a flat tangent plane. Close to the axis that plane distorted enough to cut a web loose.
- **Lighter.** Printed hull per ship:

  | Version | v0.2 / v0.1.3 | 1026 v0.2.1 |
  |---|---|---|
  | Bench, 8 thrusters | 229 cm³ | 214 cm³ |
  | Bench, 4 thrusters | 199 cm³ | 184 cm³ |
  | Kobra Max, 8 thrusters | 434 cm³ | 415 cm³ |
  | Kobra Max, 4 thrusters | 368 cm³ | 349 cm³ |
  | Double Kobra, 12 slices | 502 cm³ | 474 cm³ |

- **Float budget corrected.** The v0.2 budget measured the double Kobra's left and right slices from meshes with gaps, which undercounted the hull (350 cm³ instead of 502), so the v0.2 figure of 903 g was about 90 g light. The volume script now falls back to the CAD kernel's volume whenever a mesh isn't watertight. With the corrected count and the lighter hull:
  - The double Kobra in full-foam LW-PLA with the LiPo weighs **977 g against 1145 g of hydrogen lift: +168 g**, 44 min of flight. With the 18650 pack it's +153 g and 83 min.
  - In moderate foam it only just floats (+27 g with the LiPo, +12 g with the 18650 pack), and the 21700 pack makes it 93 g heavy, so **print it in full foam**.
  - On helium the full-foam LiPo build still floats, with about 84 g to spare.
  - The 4-thruster Kobra Max model (full foam, 503 g) hovers on its fan with 55 g to spare; the 4-thruster bench model (368 g) with 73 g.
- **Checks:**
  - Every slice and piece is a single valid solid.
  - The keel, housing and shaft are airtight, and the duct/housing joint has no leak path.
  - Nothing intrudes into the air path except the keel joint bosses.
  - Neighbouring slices overlap by 0 mm³.
  - All fit checks pass, and every print STL is watertight.

## 926 v0.2: self-contained double-Kobra build (September 2026)

A 1.58 m ship (x3.8) that carries its own battery and controller and **floats on hydrogen alone**, for indoor flights in a garage or warehouse. Everything is designed as light as it can print; stiffness comes second.

- **12 slices, 4 thrusters.** Slices come in three types: left, right (each pair closes one thrust duct) and plain (no duct). Assemble them L, R, P around the ship, four times.
- **Each slice prints in 5 pieces on a Kobra Max** (400 × 400 × 450 mm), with the largest at 386 × 86 × 208 and 187 × 307 × 395 mm.
  - The cuts are a middle band (z = ±150 mm) and a split at r = 415 mm in the top and bottom bands.
  - A peg and hole cross every cut, and the lattice has a rib on every cut line, so each piece ends in a full edge strip to glue.
- **Intake shaft as two printed tubes** (Ø66 bore, 0.86 mm wall, socket joints). They slide into sockets on the housing and the bellmouth. The bore stays smooth and empty.
- **Lightest lattice:** 1.2 mm webs instead of 2.0 mm (`OAS_RIB=1.2`), with a two-sided rib on the equator for the servo collars.
- **Thrusters:** the 8-thruster hardware (Ø24 ducts, 64 mm rings) on 4 ducts, with SG90 servos. The fan is unchanged. Together they give about 306 gf.
  - Bigger ducts and rings would give more thrust, but each size step adds about 60 g of duct wall. A ship that floats only needs the fan to manoeuvre, and 306 gf pushes it along at about 2.5 m/s.
- **Avionics tray** (24 cm³) clamped to the intake tube just above the fan housing. It has two cradles for the battery halves, one on each side for balance, and two plates for the ESC, ESP32, BEC and IMU.
- **Firmware:**
  - `OAS_DIRECT_PWM` drives the servos and ESC straight from the ESP32 (no PCA9685).
  - `OAS_THRUSTERS` / `OAS_FIRST_AZ_DEG` set the thruster layout.
  - A battery monitor on GPIO 34 stops the fan below 3.4 V per cell.
  - The mixer now uses one shared scale for all thrusters, so commands no longer cross-couple.
- **Weight:** 903 g all-up in full-foam lightweight PLA with a 1500 mAh LiPo, against 1145 g of hydrogen lift in 1022 L: **242 g to spare**. Every foam and battery option floats, with between 6 and 242 g to spare. Flight time is 44–130 min, depending on the battery. The details are in `Analysis/FLOAT.md`.
- **Fixes along the way:**
  - Wide lattice windows are cut from a faceted skin shell. The exact curved shell sometimes returned an empty cut, and the builder now warns if that ever happens. The released v0.1.3 files were checked and are unaffected.
  - Seam wedges at large sizes are no longer left solid.
  - A window cut that the CAD kernel silently skips (it happened once per slice, on the equator) is retried and flagged. The released v0.1.3 variants were checked and have none.
  - Joint bosses sit clear of the skin.
  - Pieces that mesh with gaps are repaired before export.
- **Checks:**
  - Every slice and piece is a single valid solid, and the pieces add up to their slice.
  - The keel and housing are airtight, neighbouring slices overlap by 0 mm³, every fit check passes, and all 17 print STLs are watertight.
- **Also changed:** the glue is now counted in the weight budget (epoxy on airtight seams, CA on lattice seams), so the v0.1 numbers moved by a few grams. The 4-thruster Kobra Max build in full foam now hovers with 49 g to spare.

## 926 v0.1.3: minimum-material lattice (September 2026)

- **Lattice cut on the real skin.**
  - The ovals were drawn flat at each cell's centre and cut only 4 mm deep. Where the hull curves (worst near the equator, and at Kobra Max size) the cut didn't reach the skin at the oval's ends, so the holes came out smaller than drawn and left thick material round the ovals and diamonds.
  - Each oval is now laid out on the curved skin, filling its cell and touching all four rib lines.
  - Every cut goes exactly through the skin, and is trimmed to it, so nothing inside is touched.
- **Junctions take all the spare skin.** The fixed diamond shapes are replaced by windows that take every bit of skin more than 2 mm from the ovals, including along the first and last rows.
  - What's left is a web of 2.0 mm ribs everywhere and nothing thicker.
  - The seam edge strips stay continuous.
- **Weight:** the hull loses 7% at bench size (8 thrusters: 243 → 229 cm³) and about 20–25% at Kobra Max size (4 thrusters: 495 → 368 cm³), where the old cuts fell shortest.
- **Closer to flight:**
  - The 4-thruster Kobra Max build in fully foamed lightweight PLA now weighs 539 g. With its 124 L of hydrogen (139 g, 26%) plus the fan's 419 gf, it **can hover, with 19 g to spare**. In moderate foam it's 630 g, 71 g short.
  - The bench 4-thruster build now hovers on its fan even in moderate foam.
  - The full table is in `Analysis/FLOAT.md`.
- **Fixes along the way:**
  - The cut reach grows with the window size, so the middle of big windows is cut too; at Kobra Max size, four skin patches had been left loose.
  - The STL export retries its mesh resolution until the mesh is watertight.
  - `check_fit.py` no longer crashes where a glued part only touches the hull.
- **Checks:**
  - All six slices are single valid solids that pass the airtightness and overlap checks.
  - Left and right slices mate with 0 overlap.
  - All 35 fit checks pass for all four propulsion versions, and every STL is watertight.

## v0.1.2: even lattice and thruster-ring fixes (September 2026)

- **Even lattice top and bottom.**
  - Below the equator the skin's ring ribs used to be spaced by angle, so near the equator the rows came out squat: at Kobra Max size, 37–47 mm tall by about 150 mm wide. Their flat ovals left wide, nearly solid bands.
  - Every row is now the same length along the skin, above and below the equator: about 33 mm at bench size and 73 mm at Kobra Max size. All the cells have the same proportions.
  - The equator rib, which carries the thrusters, is unchanged.
- **Thruster-ring feed fix (all versions).** The stem's feed hole was cut too deep, through the ring's inner diffuser cone, so some air could skip the Coanda slot and dump straight into the ring's centre. The feed now opens only through the ring's outer wall into its plenum, and a check confirms the cone is intact.
- **4-thruster rings** now have the same slim profile as the 8-thruster ones: 32 mm diffuser, about 39 mm tall instead of 48, 69 mm OD. The throat is 22.5 mm, the Coanda lip 3.5 mm and the slot 2.0 mm, still about 422 gf. The Ø31 stem bore turns into an oval port of the same area where it meets the ring.
- **Checks:** all six slices pass the solid, airtightness and overlap checks, and left/right mate with 0 overlap. All 35 fit checks pass for all four propulsion versions, and every STL is watertight. Weights and lift are updated in `Analysis/FLOAT.md`.

## v0.1.1: Kobra Max size, lightweight PLA and the float budget (September 2026)

**Kobra Max versions (x1.9, 790 mm across)** of both the 8- and 4-thruster designs.
- Each slice prints on an Anycubic Kobra Max: 372 × 393 × 279 mm on its 400 × 400 × 450 mm volume.
- Only the hull outline and lattice grow. Walls, ribs, joints, fan, ducts, thrusters and servos keep their size, so the hydrogen volume grows 7.5× (16 L → 124 L) while printed mass grows about 2.3×.
- All checks and the 35 fit checks pass for both.
- **Files:**
  - STL: `Print Files/PieSlice926-v0.1-8T-KobraMax.stl`, `…-4T-left-KobraMax.stl`, `…-4T-right-KobraMax.stl`
  - propulsion: `CAD Files/Propulsion/x1.9/` and `4T/x1.9/`
  - renders: `Renders/v0.1-4T-KobraMax-*.png`

**Will it float?** [Analysis/FLOAT.md](Analysis/FLOAT.md) is a new mass, hydrogen-lift and thrust budget for every version and material, generated from the CAD. Numbers are airborne and tethered.

| 4 thrusters | Mass | H₂ volume | H₂ lift | Lift ÷ mass | H₂ + fan − mass |
|---|---|---|---|---|---|
| Bench, lightweight PLA (moderate foam) | 452 g | 16.3 L | 18 g | 4% | −12 g |
| Bench, lightweight PLA (full foam) | 390 g | 16.3 L | 18 g | 5% | **+50 g (hovers with the fan)** |
| Kobra Max, lightweight PLA (moderate foam) | 742 g | 124 L | 139 g | 19% | −185 g |
| Kobra Max, lightweight PLA (full foam) | 624 g | 124 L | 139 g | 22% | −67 g |

- Floating on hydrogen alone needs about x4.1–4.6 size, a 1.7–1.9 m hull. That's a lower bound, with today's thin walls.

**Lightweight (foaming) PLA** is now a BOM option (item 13b), with print settings in the slice README.

**Fixes:** the fan hatch is rebuilt from a keel cap instead of the whole hull ellipsoid, whose degenerate pole made some exports invalid. All hatch exports are now valid and watertight.

## v0.1: two designs, 8 and 4 thrusters, and a narrower intake (September 2026)

- **Narrow intake:** the shaft is now **Ø66 all the way up** (it was Ø95, narrowing at the bottom).
  - The width was only needed to drop the impeller in from the top, and it now comes in through the keel hatch.
  - The cost is about 1% of the fan pressure. The gas cells gain about 0.6 L and the hull loses about 2 g per slice.
- **New 4-thruster design,** alongside the 8-thruster one:
  - 4 thrusters on alternate seams (at 22.5°, 112.5°, 202.5° and 292.5°), still exactly on the equator.
  - Ø34 ducts, Ø34/31 stems, 72 mm rings with a 2.0 mm slot, and 44-tooth gears, sized for twice the flow per thruster ([AIRFLOW-4T.md](Analysis/AIRFLOW-4T.md)).
  - The housing ceiling is 10 mm higher so the bigger duct mouths fit.
  - **4 left + 4 right slices**, alternating. Each pair closes one duct, and the right slice carries the servo.
  - Expected thrust ≈ 422 gf, slightly more than 8 thrusters (408 gf), with 4 fewer servos and thrusters. The hull is 12% lighter.
- **Files:**
  - `Print Files/PieSlice926-v0.1-8T.stl`, `…-4T-left.stl`, `…-4T-right.stl`
  - FreeCAD/STEP in `CAD Files/SimplifiedSlice/` and `CAD Files/Propulsion/` (4 thrusters: `4T/`)
  - renders in `Renders/`
- **Parametric:** `airship_slice.py` and `propulsion.py` build every version from `OAS_VARIANT=8T|4T`, `OAS_SIDE=L|R` and `OAS_SCALE`.
- **Checks:** every slice passes the solid, airtightness and overlap checks, and all 35 fit checks pass for both designs.
- The v0 slice STL is archived as `OldFiles/PrintFiles/PieSlice926-v0-revE.stl`.

## v0: first buildable model (September 2026)

The v0 files are archived in `OldFiles/PrintFiles/PieSlice926-v0-revE.stl`, and in the `v0` release.

The first complete, printable version of the 926 tethered bench demo. It includes the hull, the shrouded fan, 8 vectoring air-multiplier thrusters, the electronics, firmware, BOM and airflow analysis.

**Files**
- **Printable STL:**
  - Hull slice (print 8): [`OldFiles/PrintFiles/PieSlice926-v0-revE.stl`](../OldFiles/PrintFiles/PieSlice926-v0-revE.stl) (archived)
  - Propulsion parts: [`CAD Files/Propulsion/print/`](CAD%20Files/Propulsion/print)
- **CAD (FreeCAD):**
  - [`airship pie slice 926.FCStd`](CAD%20Files/SimplifiedSlice/airship%20pie%20slice%20926.FCStd)
  - [`propulsion 926.FCStd`](CAD%20Files/Propulsion/propulsion%20926.FCStd)
  - STEP files and parametric CadQuery sources sit next to them.
- **BOM:** [`Electronics/BOM.md`](Electronics/BOM.md). Core parts cost about $230–320.
- **Build notes:**
  - [slice](CAD%20Files/SimplifiedSlice/README.md)
  - [propulsion](CAD%20Files/Propulsion/README.md)
  - [electronics](Electronics/README.md)
  - [airflow analysis](Analysis/AIRFLOW.md)
  - [design constraints](DESIGN-CONSTRAINTS.md)

### Hull (slice rev E)
- **Simplified from the 125 design into 8 identical 45° slices** that plug together, with pegs on one seam and holes on the other.
- **Smooth outside:** the 207.765 × 104 mm ellipsoid. The thrust ducts run inside the skin, and only the thruster stems and servo hubs pass through it.
- **One continuous arc from keel to intake.** The top trough, shelf and lip are gone; the skin rolls into the intake shaft over a 12 mm bellmouth.
- **No decks.** Both interior floors are removed for the bench model.
- **Lattice everywhere except the air path:**
  - two columns of large oval cells with 2.0 mm ribs
  - hollow diamonds at every junction, and hollow half-diamonds on the seams
  - a continuous 1 mm edge strip along each seam
- **Smooth intake shaft:** the motor ledge and spider are gone, and nothing sits in the shaft bore.
- **Shrouded fan housing:**
  - The shaft narrows smoothly to the Ø66 impeller eye, then the housing wall turns over the blade tips with 1.5 mm clearance. This closes the 3.4 mm leak path back up the shaft.
  - The housing is only as big as the fan and the duct mouths (it meets the keel at r = 80 mm).
- **Removable fan hatch:** the keel under the fan is a bayonet hatch that carries the motor and impeller. It locks with an 11.5° clockwise turn, and the motor's torque keeps it locked.
- **Thrusters exactly on the equator (z = 0)**, for navigation.
- **0.86 mm walls** (2 perimeters, the airtight minimum on a 0.4 mm nozzle).
- **Weight:**
  - about 32 cm³ (≈ 40 g of PLA) per slice, down from 48 g in rev D, so ≈ 320 g for the hull
  - about 16 L of free interior space
- **Print setup:** each slice prints on its seam on a Prusa MK3S+, 207 × 201 × 146 mm, with supports only inside the duct arch on the bed.

### Propulsion
- **Motor:** 2207 1750 KV on 4S (≈ 32 g, ≈ 25 A peak), chosen by the airflow analysis. It replaces the A2212.
- **Impeller:** 88 mm backward-curved, printed in PETG (≈ 8 g).
  - eye Ø66, exit width 12.5 mm, blade tops following the shroud curve
  - a cup over the motor bell, clamped by the prop nut
- **8 air-multiplier thrusters:**
  - a Coanda ring with a 1.6 mm slot on a Ø25/22 stem
  - each swivels ±90° on a radial axis, driven by an MG90S servo through a 1:1 36-tooth gear pair
- **Expected thrust:** about 4.0 N (≈ 410 gf) at 15,650 rpm and 62 L/s, with a range of 306–564 gf until the bench measurements are in. A shrouded fan efficiency of 0.42 is assumed.
- **Fit checks:** `check_fit.py` runs 35 clash and clearance checks against the assembled hull, and they all pass.

### Electronics and firmware
- **Controller:** ESP32 + PCA9685, with a Wi-Fi slider control page, ESC arming and a link-loss failsafe. The mixer unit tests pass on a PC; it hasn't yet run on real hardware.
- **Power:** a 4S LiPo or a 15 V 350 W supply feeding a 45 A ESC, with a 5 V UBEC for the servos.

### Known limits
- Bench-test only: hover needs about 8.6 N, and hydrogen in the free volume lifts only about 18 g.
- The fan efficiency, air-multiplier gain and swivel leakage are estimates. Measure them on the bench and rerun `Analysis/airflow.py`.

### Earlier revisions
- **Rev A–D slices** and the older 125/1224 models are archived in [`OldFiles/`](../OldFiles) at the repository root.
- **RevB and revC have a duct leak.** Don't print them.

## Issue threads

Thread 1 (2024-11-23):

Current Model Too Heavy

crhy, 2024-11-23:
The model will print at half the current thickness, so we need to revise the entire model to be half the current thickness.

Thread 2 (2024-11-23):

Current Model won't open in FreeCAD 1.0 RC

crhy, 2024-11-23:
1024 won't open in the latest FreeCAD

crhy, 2024-11-23:
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

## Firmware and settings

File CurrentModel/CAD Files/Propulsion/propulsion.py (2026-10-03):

"""Propulsion parts for the 1026 pie-slice airship (tethered bench demo), rev E.

Air path: the impeller at the bottom of the central shaft pulls air down the
shaft and throws it outward into the plenum between the floor and the keel.
From there it enters the 8 thrust ducts, which run inside the skin to the
equator. The hull's outside stays smooth. At each seam, a rotating stem
passes through a round hole in the skin, with its flange behind a bearing
boss inside the duct, and carries a printed air-multiplier ring. An MG90S
servo inside the hull turns it through a 1:1 gear pair just outside the
skin. The swivel axis is radial, so each thruster points its jet anywhere in
the plane made of "up" and the tangential direction.

Parts (all in mm; each is exported already posed for printing):
  impeller        open, backward-curved, 88 mm; a cup over the motor bell clamps on its shaft
  fan_hatch       removable keel hatch (bayonet); the 2207 stands on it, bell up
  servo_mount     glued inside the skin; holds the MG90S, spline out
  stem            rotating swivel tube; its flange sits behind the duct's bearing boss
  stem_gear       36T m1, D-bore, glued on the stem
  servo_gear      36T m1, hub through the skin onto the MG90S spline
  thruster_ring   air multiplier: Coanda lip, 1.6 mm slot, 64 mm OD

Run: python3 propulsion.py      -> <part>.step (model coordinates) + print/<part>.step
     freecadcmd make_fcstd.py     -> propulsion 1026.FCStd + print/<part>.stl
     python3 check_fit.py         -> clash checks against the hull
"""
import math
import os
import sys

import cadquery as cq

HERE = os.path.dirname(os.path.abspath(__file__))
sys.path.insert(0, os.path.join(HERE, "..", "SimplifiedSlice"))
import airship_slice as hull  # noqa: E402

# ---- motor: 2207 1750KV racing outrunner on 4S (see Analysis/AIRFLOW.md), ~32 g
MOTOR_D = 28.0             # bell diameter
MOTOR_L = 20.0             # mount face to bell top
MOUNT_SQUARE = 16.0        # M3 holes on a 16 x 16 mm square (the usual 2207 pattern)
HUB_BORE = 5.2             # M5 motor shaft

# ---- fan hatch: the keel under the fan, removable; the motor stands on it
# The impeller's cup sits on the bell top and is clamped by the prop nut, so
# the bell top sets the impeller height: the blade tips run SHROUD_GAP under
# the housing's shroud.
CUP_TOP_T = 2.0            # cup top disc (clamped between bell and nut)
CUP_R = 15.5               # cup wall inner radius (bell is 14)
IMP_B2 = 12.5                  # blade height at the tip (from the airflow analysis); the
                               # inlet edge is taller, following the housing's shroud
IMP_PLATE_TOP = hull.FLOOR_Z - hull.SHROUD_GAP - IMP_B2
BELL_TOP = IMP_PLATE_TOP + 5.2   # the nut sits in the eye, under the contraction
PED_TOP = BELL_TOP - MOTOR_L
PED_R = 20.0               # motor pedestal drum on the hatch
PED_PLATE = 2.0
HATCH_CLR = 0.2            # hatch dish to keel opening, per side
FLANGE_Z = (hull.LUG_Z[1] + 0.2, hull.LUG_Z[1] + 1.7)   # bayonet tabs ride on the lugs
TAB_HALF = 14.0 * 8 / hull.N    # one tab per slice, centred on the seams when inserted
LOCK_TURN = 11.5 * 8 / hull.N   # degrees clockwise (from above) from insert to locked
WIRE_HOLE = (25.0, 3.0)    # phase-wire hole through the dish: radius, hole radius

# ---- impeller ---------------------------------------------------------------
IMP_R1, IMP_R2 = 33.0, 44.0    # eye (blade inlet) / tip radius (OD 88 passes the Ø94 keel hatch opening)
IMP_BLADES = 7
IMP_PLATE = 0.8                # backplate: 4 layers; the blades stiffen it
IMP_T = 0.86                   # blade thickness (2 lines)
IMP_BETA = 40.0                # backward sweep of the blade, degrees
IMP_SCALLOP_MARGIN = 2.0       # backplate kept this far beyond each blade face
IMP_SCALLOP_R = 38.0           # scallops start here (the eye and inner passages keep a full floor)

# ---- swivel and servo (outlet frame: X = radial along the seam, Z = up) ----
# The hull stays smooth: only the stem (on the seam) and the servo's gear hub
# (SERVO_Y to the side) pass through round holes in the skin. The stem's
# flange sits behind the bearing boss inside the duct; the servo hangs inside
# the hull on a mount glued to the skin; the gear pair runs just outside.
OUT_Z = hull.OUT_Z         # swivel axis height
X_SKIN = hull.hull_r(OUT_Z)                 # skin at the stem, on the seam
X_BOSS = X_SKIN - hull.BOSS_LEN             # inner face of the bearing boss
FOUR = hull.FOUR           # OAS_VARIANT=4T: 4 thrusters
LARGE = hull.LARGE         # large thruster hardware, sized for twice the flow each
STEM_OD, STEM_ID = (34.0, 31.0) if LARGE else (25.0, 22.0)   # bore: see Analysis/AIRFLOW*.md
FLANGE_D, FLANGE_T = STEM_OD + 3.0, 1.8    # sits in the duct's end bulb, behind the bearing sleeve
D_FLAT = 0.7               # depth of the stem's D-flat that keys the gear
GEAR_M, GEAR_Z, GEAR_T = 1.0, (44 if LARGE else 36), 4.0   # 4T: 44T to clear the Ø34 stem
GEAR_X = X_SKIN + 1.235    # hull-side face of both gears, just outside the skin
SERVO_Y = hull.SERVO_T     # 1:1 pair: centre distance = pitch diameter
assert abs(SERVO_Y - GEAR_M * GEAR_Z) < 1e-6
MG90S = dict(body=(22.8, 12.2), tabs=32.3, hole_pitch=27.8, shaft_offset=5.4,
             below_tabs=16.0, above_tabs=4.5, spline_tip=11.5, spline_d=4.8)
TAB_X = X_SKIN - 15.265    # servo tab plane: the body top clears the curved skin
MOUNT_T = 3.0

# ---- air multiplier ring ----------------------------------------------------
RT, RO = (22.5, 34.5) if LARGE else (20.0, 32.0)   # throat radius at the slot, outer radius
HD = 32.0                  # diffuser height (exit at a = 0, slot near the top)
TAPER = 15.0               # diffuser half-angle
RC = 3.5 if LARGE else 3.0  # Coanda lip radius
SLOT = 2.0 if LARGE else (1.2 if hull.N != 8 else 1.6)   # from the airflow analysis (shrouded fan)
RING_W = 0.86              # 2 perimeters
STEM_IN = RO + (16.0 if LARGE else 12.0)   # stem socket end, from the ring axis (4T: room to
                                          # reshape the round stem bore into the oval port)


# ---- helpers ----------------------------------------------------------------
def revolve(pts, arcs=()):
    """Revolve a closed (radius, z) polyline 360 deg about Z."""
    w = cq.Workplane("XZ").polyline(pts).close()
    return w.revolve(360, (0, 0, 0), (0, 1, 0)).val()


def spur_gear(z, m, t, bore=None, hub_r=10.0):
    """Involute spur gear, flat on XY, `t` thick."""
    rp, ra, rf = m * z / 2, m * z / 2 + m, m * z / 2 - 1.25 * m
    rb = rp * math.cos(math.radians(20))

    def inv(r):
        a = math.acos(min(1.0, rb / r))
        return math.tan(a) - a

    half = math.pi / (2 * z) + inv(rp)          # half tooth angle at base circle
    pts = []
    for i in range(z):
        c = 2 * math.pi * i / z
        flank = [max(rb, rf) + (ra - max(rb, rf)) * k / 6 for k in range(7)]
        left = [(r, c - half + inv(r)) for r in flank]
        right = [(r, c + half - inv(r)) for r in reversed(flank)]
        root = [(rf, c - half - 0.6 * math.pi / z * 0.5)]
        for r, a in root + left + right:
            pts.append((r * math.cos(a), r * math.sin(a)))
    g = cq.Workplane("XY").polyline(pts).close().extrude(t)
    if bore:
        g = g.cut(bore)
    if rf - 2 - hub_r >= 3.0:                           # room for lightening holes?
        for k in range(6):
            a = 2 * math.pi * k / 6
            rr = (rf - 2 + hub_r) / 2                   # between hub and root
            g = g.cut(cq.Workplane("XY").center(rr * math.cos(a), rr * math.sin(a))
                        .circle((rf - 2 - hub_r) / 2).extrude(t))
    return g.val()


def d_bore(d, flat, t):
    c = cq.Workplane("XY").circle(d / 2).extrude(t)
    return c.cut(cq.Workplane("XY").center(d / 2 + d / 2 - flat, 0)
                  .rect(d, d).extrude(t)).val()


def hull_envelope(margin=0.0):
    """The whole hull, as a solid, optionally grown by `margin`."""
    a = hull.arc(hull.A + margin, hull.B + margin, -math.pi / 2, math.pi / 2)
    wire = cq.Wire.assembleEdges(hull.parts_to_edges([a]))
    return cq.Solid.revolve(cq.Face.makeFromWires(wire), 360,
                            cq.Vector(), cq.Vector(0, 0, 1))


# ---- impeller and motor pedestal (hull coordinates, axis = Z) ---------------
def keel_cap(margin=0.0, r_max=70.0, height=60.0):
    """The bottom of the hull (grown by `margin`) out to r_max, as a solid of
    revolution. Unlike the whole ellipsoid, it has no degenerate top pole."""
    a, b = hull.A + margin, hull.B + margin
    p1 = -math.acos(r_max / a)
    return hull.wedge_edges(hull.arc(a, b, -math.pi / 2, p1),
                            (r_max, -hull.B + height), (0, -hull.B + height), half=180.0)


def fan_hatch(locked=True):
    """The keel under the fan: a dish flush with the hull, a spigot wall and 8
    bayonet tabs, and the motor pedestal. Insert it with the tabs on the seams,
    push up, and turn it LOCK_TURN clockwise (from above) onto the lugs until
    the tabs hit the stop posts. The motor's reaction torque (the impeller
    turns counter-clockwise) holds it against the posts; the housing pressure
    holds the tabs down on the lugs. Tape the outside seam for the air seal."""
    r_d = hull.HATCH_R - HATCH_CLR
    shell = keel_cap(0).cut(keel_cap(-hull.T))
    dish = shell.intersect(cq.Solid.makeCylinder(r_d, 20, cq.Vector(0, 0, -hull.B - 5)))
    inside = keel_cap(-hull.T / 2)
    spigot = cq.Solid.makeCylinder(hull.LUG_R - 0.2, FLANGE_Z[1] + hull.B + 1,
                                   cq.Vector(0, 0, -hull.B - 1)).cut(
        cq.Solid.makeCylinder(hull.LUG_R - 0.2 - hull.T, 30, cq.Vector(0, 0, -hull.B - 1))).intersect(inside)
    ring = cq.Solid.makeCylinder(hull.HATCH_R - 0.4, FLANGE_Z[1] - FLANGE_Z[0],
                                 cq.Vector(0, 0, FLANGE_Z[0])).cut(
        cq.Solid.makeCylinder(hull.LUG_R - 0.4, 10, cq.Vector(0, 0, FLANGE_Z[0] - 5)))
    tabs = None
    for k in range(hull.N):
        sector = hull.wedge([(0, FLANGE_Z[0] - 1), (60, FLANGE_Z[0] - 1), (60, FLANGE_Z[1] + 1),
                             (0, FLANGE_Z[1] + 1)], half=TAB_HALF).rotate(
            (0, 0, 0), (0, 0, 1), hull.HALF + 360.0 / hull.N * k)
        t_ = ring.intersect(sector)
        tabs = t_ if tabs is None else tabs.fuse(t_)
    drum = cq.Solid.makeCylinder(PED_R, PED_TOP + hull.B + 1, cq.Vector(0, 0, -hull.B - 1)).intersect(inside)
    drum = drum.cut(cq.Solid.makeCylinder(PED_R - hull.T, PED_TOP - PED_PLATE + hull.B + 1,
                                          cq.Vector(0, 0, -hull.B - 1)))
    body = dish.fuse(spigot, tabs, drum)
    body = body.cut(cq.Solid.makeCylinder(4.5, 10, cq.Vector(0, 0, PED_TOP - 5)))   # circlip
    for k in range(4):
        a = math.radians(45 + 90 * k)
        c = MOUNT_SQUARE / math.sqrt(2)
        body = body.cut(cq.Solid.makeCylinder(1.7, 10, cq.Vector(c * math.cos(a), c * math.sin(a),
                                                                 PED_TOP - 5)))
    body = body.cut(cq.Solid.makeCylinder(WIRE_HOLE[1], 20, cq.Vector(WIRE_HOLE[0], 0, -hull.B - 5)))
    body = body.clean()
    return body.rotate((0, 0, 0), (0, 0, 1), -LOCK_TURN) if locked else body


def impeller_z():
    """Top of the blades, and the backplate underside, in hull z."""
    base = IMP_PLATE_TOP - IMP_PLATE
    return blade_top(IMP_R1), base


def blade_top(r):
    """Blade top edge: the housing's shroud curve, SHROUD_GAP below it (normal to it)."""
    zc = hull.FLOOR_Z + hull.SHROUD_RC                 # centre of the shroud turn
    rc = hull.EYE_R + hull.SHROUD_RC
    if r >= rc:
        return hull.FLOOR_Z - hull.SHROUD_GAP
    R = hull.SHROUD_RC + hull.SHROUD_GAP
    return zc - math.sqrt(max(R * R - (rc - r) ** 2, 0.0))


def impeller():
    top, base = impeller_z()
    plate = cq.Solid.makeCylinder(IMP_R2, IMP_PLATE, cq.Vector(0, 0, base))
    # scalloped rim: the backplate is cut away between neighbouring blades from
    # IMP_SCALLOP_R out to the rim, keeping a strip under each blade
    sweep = math.radians(IMP_BETA)
    ang = lambda k, r: (2 * math.pi * k / IMP_BLADES
                        - sweep * (min(max(r, IMP_R1), IMP_R2) - IMP_R1) ** 1.3
                        / (IMP_R2 - IMP_R1) ** 1.3)
    keep = IMP_T / 2 + IMP_SCALLOP_MARGIN
    rs = [IMP_SCALLOP_R + (IMP_R2 + 2 - IMP_SCALLOP_R) * i / 12 for i in range(13)]
    for k in range(IMP_BLADES):
        lead = [(r * math.cos(ang(k, r) + keep / r), r * math.sin(ang(k, r) + keep / r)) for r in rs]
        trail = [(r * math.cos(ang(k + 1, r) - keep / r), r * math.sin(ang(k + 1, r) - keep / r))
                 for r in reversed(rs)]
        def arc_(r, a0, a1, n=10):                   # the scallop's ends follow circles
            return [(r * math.cos(a0 + (a1 - a0) * j / n), r * math.sin(a0 + (a1 - a0) * j / n))
                    for j in range(1, n)]
        r_out, r_in = rs[-1], rs[0]
        outer = arc_(r_out, ang(k, r_out) + keep / r_out, ang(k + 1, r_out) - keep / r_out)
        inner = arc_(r_in, ang(k + 1, r_in) - keep / r_in, ang(k, r_in) + keep / r_in)
        scallop = (cq.Workplane("XY").workplane(offset=base - 0.5)
                     .polyline(lead + outer + trail + inner).close().extrude(IMP_PLATE + 1).val())
        plate = plate.cut(scallop)
    # cup over the motor bell: the backplate opens inside it, and its top disc
    # sits on the bell and is clamped by the prop nut
    plate = plate.cut(cq.Solid.makeCylinder(CUP_R, 5, cq.Vector(0, 0, base - 1)))
    cup = cq.Solid.makeCylinder(CUP_R + IMP_T, BELL_TOP + CUP_TOP_T - base, cq.Vector(0, 0, base)).cut(
        cq.Solid.makeCylinder(CUP_R, BELL_TOP - base, cq.Vector(0, 0, base)))
    body = plate.fuse(cup)
    # the blade tops follow the housing's shroud, SHROUD_GAP below it
    prof = [(IMP_R1 - 3 + (IMP_R2 + 8 - IMP_R1) * i / 40, 0) for i in range(41)]
    prof = [(r, blade_top(r)) for r, _ in prof]
    cutter = cq.Workplane("XZ").polyline(
        prof + [(prof[-1][0], top + 20), (prof[0][0], top + 20)]).close() \
        .revolve(360, (0, 0, 0), (0, 1, 0)).val()
    # blade: circular arc from r1 to r2, swept back by IMP_BETA
    for k in range(IMP_BLADES):
        a0 = 2 * math.pi * k / IMP_BLADES
        mid = [(IMP_R1 + (IMP_R2 - IMP_R1) * i / 8,
                a0 - sweep * (i / 8) ** 1.3) for i in range(9)]
        side = []
        for sgn in (1, -1):
            for r, a in (mid if sgn > 0 else reversed(mid)):
                da = sgn * IMP_T / 2 / r
                side.append((r * math.cos(a + da), r * math.sin(a + da)))
        blade = (cq.Workplane("XY").workplane(offset=base + IMP_PLATE)
                   .polyline(side).close().extrude(top - base + 5).val())
        body = body.fuse(blade.cut(cutter))
    body = body.cut(cq.Solid.makeCylinder(HUB_BORE / 2, 30, cq.Vector(0, 0, base - 5)))
    return body.clean()


# ---- thruster outlet: local frame, X = radial along the seam, Z = up -------
def servo_mount():
    """Cradle glued to the inside of the skin; the MG90S hangs in it, spline out.

    The servo drops in from the hull side and is held by two M2 screws driven
    from inside the hull through the plate into its tabs.
    """
    b, w = MG90S["body"]
    cz = OUT_Z + MG90S["shaft_offset"]              # body centre (spline is off-centre)
    inside = hull_envelope(-hull.T)
    shell = cq.Solid.makeBox(20, w + 12, MG90S["tabs"] + 10,
                             cq.Vector(TAB_X - MOUNT_T, SERVO_Y - w / 2 - 6, cz - MG90S["tabs"] / 2 - 5))
    hollow = cq.Solid.makeBox(20, w + 8, MG90S["tabs"] + 6,
                              cq.Vector(TAB_X, SERVO_Y - w / 2 - 4, cz - MG90S["tabs"] / 2 - 3))
    body = shell.intersect(inside).cut(hollow)
    body = body.cut(cq.Solid.makeBox(10, w + 0.4, b + 0.4,
                                     cq.Vector(TAB_X - 8, SERVO_Y - w / 2 - 0.2, cz - b / 2 - 0.2)))
    for s_ in (1, -1):
        body = body.cut(cq.Solid.makeCylinder(0.8, 10, cq.Vector(TAB_X - 8, SERVO_Y,
                        cz + s_ * MG90S["hole_pitch"] / 2), cq.Vector(1, 0, 0)))
    # windows in the side walls let glue squeeze out and save a little weight
    return body.clean()


def servo_dummy():
    """MG90S envelope, for fit checks."""
    b, w = MG90S["body"]
    cz = OUT_Z + MG90S["shaft_offset"]
    body = cq.Solid.makeBox(MG90S["below_tabs"] + MG90S["above_tabs"], w, b,
                            cq.Vector(TAB_X - MG90S["below_tabs"], SERVO_Y - w / 2, cz - b / 2))
    tabs = cq.Solid.makeBox(2.5, w, MG90S["tabs"], cq.Vector(TAB_X, SERVO_Y - w / 2, cz - MG90S["tabs"] / 2))
    spline = cq.Solid.makeCylinder(MG90S["spline_d"] / 2, MG90S["spline_tip"] - MG90S["above_tabs"],
                                   cq.Vector(TAB_X + MG90S["above_tabs"], SERVO_Y, OUT_Z), cq.Vector(1, 0, 0))
    return body.fuse(tabs, spline)


def stem():
    """Rotating swivel tube; its flange sits behind the bearing boss in the duct."""
    x0 = X_BOSS - FLANGE_T - 0.3
    length = (GEAR_X + GEAR_T + 3) - x0 + 8          # into the ring socket by 8
    ax = cq.Vector(1, 0, 0)
    tube = cq.Solid.makeCylinder(STEM_OD / 2, length, cq.Vector(x0, 0, OUT_Z), ax)
    flange = cq.Solid.makeCylinder(FLANGE_D / 2, FLANGE_T, cq.Vector(x0, 0, OUT_Z), ax)
    body = tube.fuse(flange)
    flat = cq.Solid.makeBox(GEAR_T + 2, 2 * STEM_OD, 3,
                            cq.Vector(GEAR_X - 1, -STEM_OD, OUT_Z + STEM_OD / 2 - D_FLAT))
    body = body.cut(flat)
    return body.cut(cq.Solid.makeCylinder(STEM_ID / 2, length + 2,
                                          cq.Vector(x0 - 1, 0, OUT_Z), ax)).clean()


def on_axis(g, y):
    """Gear built flat on XY (thickness +Z) -> hull-side face at GEAR_X, axis X."""
    return g.rotate((0, 0, 0), (0, 1, 0), 90).translate((GEAR_X, y, OUT_Z))


def stem_gear():
    bore = d_bore(STEM_OD + 0.2, D_FLAT + 0.1, GEAR_T)
    return on_axis(spur_gear(GEAR_Z, GEAR_M, GEAR_T, bore, hub_r=STEM_OD / 2 + 1.5), 0)


def servo_gear():
    """36T gear with a hub that reaches through the skin onto the MG90S spline.

    Press it on the spline and fix it with the servo's M2 horn screw from outside.
    """
    hub_len = GEAR_X - (TAB_X + MG90S["spline_tip"] - 3.0)   # 3 mm on the spline
    g = spur_gear(GEAR_Z, GEAR_M, GEAR_T)
    hub = cq.Solid.makeCylinder(3.7, hub_len, cq.Vector(0, 0, -hub_len))
    g = g.fuse(hub)
    g = g.cut(cq.Solid.makeCylinder(MG90S["spline_d"] / 2, 3.0, cq.Vector(0, 0, -hub_len)))  # slip fit + glue
    g = g.cut(cq.Solid.makeCylinder(1.1, hub_len + GEAR_T, cq.Vector(0, 0, -hub_len)))
    g = g.cut(cq.Solid.makeCylinder(2.2, 2.0, cq.Vector(0, 0, GEAR_T - 2.0)))  # screw head
    return on_axis(g, SERVO_Y)
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

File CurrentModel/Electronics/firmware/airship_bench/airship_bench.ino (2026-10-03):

// OpenAirShips 1026 firmware: tethered bench demo and self-contained builds.
//
// The ESP32 opens a Wi-Fi access point "OpenAirShip" (password below).
// Browse to http://192.168.4.1 for sliders: fan throttle, lift, surge, sway
// and yaw. The mixer (mixer.h) turns those into swivel angles.
//
// Outputs, chosen at build time:
// - default: a PCA9685 board. Channels 0..N-1 drive the swivel servos and
//   channel 8 drives the fan's ESC.
// - OAS_DIRECT_PWM: the ESP32 drives the servos and ESC itself (LEDC, 50 Hz),
//   with no PCA9685 board. Lighter, for self-contained builds; pins below.
// Thruster layout: OAS_THRUSTERS / OAS_FIRST_AZ_DEG (see mixer.h). For the
// 12-slice, 4-thruster double-Kobra build, put these three lines at the top:
//   #define OAS_DIRECT_PWM
//   #define OAS_THRUSTERS 4
//   #define OAS_FIRST_AZ_DEG 15.0f
// Battery (self-contained builds): the pack voltage through a 100k/22k
// divider on BATT_PIN. Below BATT_CUTOFF_V per cell the fan stops and the
// servos centre, so the pack isn't over-discharged.
//
// Safety: the fan stays at zero until you press ARM. It returns to zero if
// the page stops sending for FAILSAFE_MS, or when you press STOP. Remove
// the impeller for first power-up and for calibrating the ESC.
//
// Libraries: "Adafruit PWM Servo Driver Library" (PCA9685 builds only); WiFi
// and WebServer come with the ESP32 core (3.x). Board: "ESP32 Dev Module".
#include <WiFi.h>
#include <WebServer.h>
#ifndef OAS_DIRECT_PWM
#include <Wire.h>
#include <Adafruit_PWMServoDriver.h>
#endif
#include "mixer.h"

// ---- configuration ---------------------------------------------------------
const char* AP_SSID = "OpenAirShip";
const char* AP_PASS = "airship926";       // change me (8+ characters)
const uint8_t ESC_CHANNEL = 8;           // PCA9685 channel
#ifdef OAS_DIRECT_PWM
const uint8_t SERVO_PINS[8] = {25, 26, 27, 14, 16, 17, 18, 19};   // thruster i on SERVO_PINS[i]
static_assert(mixer::kThrusters <= 8, "one servo pin per thruster");
const uint8_t ESC_PIN = 13;
#endif
const int BATT_PIN = 34;                  // ADC via a 100k / 22k divider (-1: no battery)
const int BATT_CELLS = 4;
const float BATT_DIVIDER = (100.0f + 22.0f) / 22.0f;
const float BATT_CUTOFF_V = 3.4f;         // per cell
const int ESC_MIN_US = 1000, ESC_MAX_US = 2000;
const float THROTTLE_LIMIT = 0.6f;        // bench cap; raise once the fan is proven
const uint32_t FAILSAFE_MS = 1000;
const float SERVO_TRIM_DEG[mixer::kThrusters] = {};   // per-servo trim, degrees

// ---- state -----------------------------------------------------------------
#ifndef OAS_DIRECT_PWM
Adafruit_PWMServoDriver pwm(0x40);
#endif
WebServer server(80);
mixer::Command cmd;
float throttle = 0.0f;
bool armed = false;
bool battLow = false;
float battVolts = 0.0f;
uint32_t lastCommandMs = 0;

#ifdef OAS_DIRECT_PWM
void writeUs(uint8_t pin, int us) {
  // 50 Hz frame = 20000 us across 2^14 ticks
  ledcWrite(pin, (uint32_t)us * 16384UL / 20000UL);
}
#else
void writeUs(uint8_t ch, int us) {
  // 50 Hz frame = 20000 us across 4096 ticks
  pwm.setPWM(ch, 0, (uint16_t)((uint32_t)us * 4096UL / 20000UL));
}
#endif

void applyOutputs() {
  for (int i = 0; i < mixer::kThrusters; ++i) {
    int us = mixer::pulseUs(battLow ? 0.0f : mixer::angleDeg(cmd, i), SERVO_TRIM_DEG[i]);
#ifdef OAS_DIRECT_PWM
    writeUs(SERVO_PINS[i], us);
#else
    writeUs(i, us);
#endif
  }
  float t = (armed && !battLow) ? mixer::clampf(throttle, 0, 1) * THROTTLE_LIMIT : 0.0f;
  int esc = ESC_MIN_US + (int)(t * (ESC_MAX_US - ESC_MIN_US));
#ifdef OAS_DIRECT_PWM
  writeUs(ESC_PIN, esc);
#else
  writeUs(ESC_CHANNEL, esc);
#endif
}

void checkBattery() {
  if (BATT_PIN < 0) return;
  battVolts = analogReadMilliVolts(BATT_PIN) / 1000.0f * BATT_DIVIDER;
  if (battVolts > 1.0f && battVolts < BATT_CUTOFF_V * BATT_CELLS && !battLow) {
    battLow = true;                        // stays latched until reset
    armed = false;
    applyOutputs();
    Serial.printf("battery low (%.2f V): fan stopped\n", battVolts);
  }
}

float arg(const char* name, float fallback) {
  return server.hasArg(name) ? server.arg(name).toFloat() : fallback;
}

void handleCommand() {
  throttle = mixer::clampf(arg("t", throttle), 0, 1);
  cmd.lift = mixer::clampf(arg("l", cmd.lift), -1, 1);
  cmd.surge = mixer::clampf(arg("x", cmd.surge), -1, 1);
  cmd.sway = mixer::clampf(arg("y", cmd.sway), -1, 1);
  cmd.yaw = mixer::clampf(arg("n", cmd.yaw), -1, 1);
  if (server.hasArg("arm")) armed = server.arg("arm") == "1";
  lastCommandMs = millis();
  applyOutputs();
  String json = "{\"armed\":" + String(armed ? "true" : "false") +
                ",\"battery\":" + String(battVolts, 2) + ",\"battLow\":" + String(battLow ? "true" : "false") +
                ",\"angles\":[";
  for (int i = 0; i < mixer::kThrusters; ++i)
    json += String(mixer::angleDeg(cmd, i), 1) + (i < mixer::kThrusters - 1 ? "," : "]}");
  server.send(200, "application/json", json);
}

const char PAGE[] PROGMEM = R"HTML(<!doctype html><meta name=viewport content="width=device-width">
<title>OpenAirShip bench</title><style>body{font:16px sans-serif;margin:16px}label{display:block;margin:14px 0 4px}
input{width:100%}button{font-size:18px;padding:10px 20px;margin:8px 8px 0 0}#s{font-family:monospace}</style>
<h2>OpenAirShip 1026</h2>
<button onclick="arm(1)">ARM</button><button onclick="arm(0)" style="background:#e33;color:#fff">STOP</button>
<label>Fan throttle <span id=tv>0</span></label><input id=t type=range min=0 max=1 step=0.01 value=0>
<label>Lift</label><input id=l type=range min=-1 max=1 step=0.05 value=1>
<label>Surge (X)</label><input id=x type=range min=-1 max=1 step=0.05 value=0>
<label>Sway (Y)</label><input id=y type=range min=-1 max=1 step=0.05 value=0>
<label>Yaw</label><input id=n type=range min=-1 max=1 step=0.05 value=0>
<p id=s></p><script>
let a=null;const q=i=>document.getElementById(i);
function send(){let u='/cmd?'+['t','l','x','y','n'].map(k=>k+'='+q(k).value).join('&');
if(a!==null){u+='&arm='+a;a=null}q('tv').textContent=q('t').value;
fetch(u).then(r=>r.json()).then(j=>q('s').textContent=(j.battLow?'BATTERY LOW ':'')+(j.armed?'ARMED ':'safe ')+(j.battery>1?j.battery.toFixed(1)+' V ':'')+'angles '+j.angles.join(' ')).catch(()=>q('s').textContent='no link')}
function arm(v){if(!v)q('t').value=0;a=v;send()}
setInterval(send,200);</script>)HTML";
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

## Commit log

2023-01-10 Initial Upload
    This design needs a lot of work still. There is no ducting, and ducting will be the main mechanism for propulsion, lift, everything.
    [AirShipComponentC-Body.stl]
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2023-06-23 Add files via upload
    Mild Update. Still broken, but have some constraints now....
    [AirShipComponentC623.FCStd]
2023-06-27 Add files via upload
    The latest Printable Component as of June 26, 2023
    [airship_pie-slice_obelisk 626.FCStd]
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2023-12-11 Add files via upload
    Still a lot of issues with this model, but we're making progress!
    [PieSlice1223.FCStd]
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2024-11-29 Rename CurrentModel/airship pie slice 1024-Hull.stl to CurrentModel/Print Files/airship pie slice 1024-Hull.stl
    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
    [airship pie slice 1024-Hull.stl]
2024-11-29 Rename CurrentModel/airship pie slice 1024thin.FCStd to CurrentModel/CAD Files/airship pie slice 1024thin.FCStd
    Organization
    [airship pie slice 1024thin.FCStd]
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2024-12-02 Delete CurrentModel/CAD Files/airship pie slice 1024thin.FCStd
    something broke. Reuploading
    [airship pie slice 1024thin.FCStd]
2024-12-02 Delete CurrentModel/CAD Files/airship_pie-slice_924c.FCStd
    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
    [airship_pie-slice_924c.FCStd]
2024-12-28 Add files via upload
    This file still has a recompute issue, I was unable to print it. And the pegs and holes don't export to the STL.
2024-12-28 Rename airship pie slice 1024.FCStd to airship pie slice 1024.FCStd
    Move deprecated to OLD
    [airship pie slice 1024.FCStd]
2024-12-28 Update and rename airship pie slice 1024-Hull.stl to airship pie slice 1024-Hull.stl
    move deprecated to OLD
    [airship pie slice 1024-Hull.stl]
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2024-12-28 Add files via upload
    Current file has many problems. See https://discord.gg/xFWErYGvyf for more info. Help!
    [PieSlice1224.stl]
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2026-09-14 Publish redesigned OpenAirShips site
    [openairship-wedge.stl]
2026-09-26 Add simplified, lightweight 8-way pie slice (from pie slice 125)
    Rebuilds the slice as a clean parametric CadQuery model: the same hull
    ellipse and 0.625 mm wall, with one regular round-cornered window frame.
    The thrust half-ducts are kept exactly as they were. Pegs sit on the
    +22.5 deg seam and holes on the -22.5 deg seam, so 8 identical slices plug
    together. Volume per slice drops from 27.2 to 21.4 cm3.
    Claude-Session: https://claude.ai/code/session_01Hh3x4wdosRWefN1xTTDzsy
    [PieSlice125-simplified.stl, airship_slice.step]
2026-09-26 Pie slice 926: FreeCAD file, print-ready for the MK3S+, airtight air path
    - Rename to the 926 date convention and add a FreeCAD document (Body on the
    part, plus a parameter sheet)
    - Walls are now 0.86 mm, exactly 2 perimeters of 0.45 mm
    - Windows have pointed tops and no flat ceilings. Laid on the hole seam, the
    frame prints without supports; only the thrust-duct arch needs them
    - The shaft, floor and keel are solid: they are the impeller duct and the
    plenum that feeds the thrust pipes. Joint holes keep 0.6 mm of wall
    - Pegs and holes have 0.15 mm clearance and 0.4 mm chamfers
    - The skin uses exact ellipse surfaces (234 faces)
    - The print STL comes out of FreeCAD's mesher, laid flat an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
    [PieSlice125-simplified.stl, PieSlice926.stl, airship pie slice 926.FCStd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]
2026-09-26 Propulsion v0: impeller, motor spider, thrust-vectoring air multipliers, electronics, BOM
    - Slice 926: a motor-spider ledge inside the shaft, and solid skin under the
    thruster outlet hoods
    - Propulsion (CadQuery source, STEP, FreeCAD file, watertight print STLs):
    - an 88 mm open centrifugal impeller and a spider for an A2212 motor; the
    unit drops in through the shaft
    - per seam: an outlet hood with a swivel sleeve and MG90S bracket, a stem,
    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
    [PieSlice926.stl, airship pie slice 926.FCStd, airship pie slice 926.step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]
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2026-09-26 Rev B: smooth hull, with the thrust ducts moved inside the skin
    - The original thrust pipes bulged out through the hull. They are replaced
    by parametric 24 mm ducts that run entirely inside the skin (keel ->
    side -> equator), split by the seam plane
    - The outside is now the plain ellipsoid. At each outlet the only openings
    are a 16.4 mm stem hole (with a bearing boss behind it in the duct) and an
    8 mm hole for the servo gear hub
    - Propulsion: the outlet hood is gone. A servo_mount is glued inside the
    skin; the servo gear's hub reaches through the skin to the spline; the stem
    flange sits behind the boss. check_fit.py passes across -90..+90 deg
    - Print STL: PieSlice926clauderevB.st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
    [PieSlice926clauderevB.stl, airship pie slice 926.FCStd, airship pie slice 926.step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]
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2026-09-27 Rev C: back to the 125 layout, cleaned up, with a sparser upper lattice
    - 125's skin lattice as a regular grid: two full-width slots between the
    floor and the main deck, then two columns of rounded windows either side
    of a centre rib (3 middle rows, and 2 larger rows up top where 125 had 4)
    - Restores 125's lower deck at z -55, the rolled double-wall rim at the top
    opening, and the deck window grids (rings every 24 mm)
    - Keeps rev B's smooth outside (ducts inside the skin), the airtight
    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
    [PieSlice926clauderevC.stl, airship pie slice 926.FCStd, airship pie slice 926.step]
2026-09-27 Rev D: oval upper lattice with hollow diamond junctions, lattice over the ducts
    - Above the main deck: 6 rows of two side columns of ovals either side of a
    centre rib (bottom row rounded rectangles), as sketched. Each four-oval
    junction gets its own diamond window with a full 4 mm rib all round
    - The big solid skin patches over the ducts and servo are gone. The lattice
    runs over the ducts (their walls stay airtight); only small collars remain
    around the stem and servo holes
    - Fixes a leak in revB/C: the stem hole was drilled through the back wall
    of the duct. The duct walls now have no openings except the stem holes
    - Print STL: PieSlice926clauderevD.stl (48.7 cm3, watertight); che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
    [PieSlice926clauderevD.stl, airship pie slice 926.FCStd, airship pie slice 926.step]
2026-09-27 Rev D: lighter lattice with 2.5 mm ribs, full ovals and hollow junctions
    - All ribs are now 2.5 mm (seam half-ribs are 1.25 mm per slice)
    - Two side columns of full (superellipse) ovals from the main deck to the
    trough, plus a row in the skin above the trough
    - Hollow diamond junctions on the centre rib and, half per slice, on the
    seams. The two skin peg joints that sat there are removed; the seam ribs
    and duct walls glue along their length
    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
    [PieSlice926clauderevD.stl, airship pie slice 926.FCStd, airship pie slice 926.step]
2026-09-27 Rev D: continuous side edges, bigger junction diamonds, 2.0 mm ribs
    - The seam half-diamonds stop RIB/2 short of the seam, so each slice's
    side edge is a continuous strip (broken only by the stem hole)
    - Ovals taper toward their tips (OVAL_N 1.8), leaving room for larger
    junction diamonds; lighter than the fuller ovals
    - Ribs are 2.0 mm (still 0.86 mm, 2-perimeter walls); oval tips and
    diamond corners point up in the print pose, so no bridging
    - 38.2 cm3 per slice (was 40.7). Keel/floor/ducts still airtight,
    check_fit passes, STL watertight
    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
    [PieSlice926clauderevD.stl, airship pie slice 926.FCStd, airship pie slice 926.step]
2026-09-27 Put the thruster axis on a ring rib, so the servo-hole collar isn't a floating ring
    The stem and servo holes were at z -13, inside a window, which left the
    servo-hub collar as a loose ring. The axis now sits on the ring rib at
    z -18.3, so both collars are part of that rib. The servo tab plane and the
    stem flange are adjusted to clear the skin and the duct; check_fit passes
    and the propulsion parts are regenerated.
    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
    [PieSlice926clauderevD.stl, airship pie slice 926.FCStd, airship pie slice 926.step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]
2026-09-27 Thin bearing sleeve behind the stem hole; document minimum wall thickness
    - The stem hole's backing boss inside the duct is now a 1.3 mm sleeve, not
    a 22 mm solid block (its skin collar shrinks with it). Duct bore stays
    24 mm
    - All air-path walls (duct, keel, floor, shaft) are confirmed at 0.86 mm =
    2 perimeters, the minimum for reliable airtight FDM parts
    - Regenerated the FreeCAD file, STEP and watertight print STL (38.1 cm3 by
    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
    [PieSlice926clauderevD.stl, airship pie slice 926.FCStd, airship pie slice 926.step]
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2026-09-27 Lighter impeller: 12.0 g -> 5.9 g
    - 0.8 mm backplate (4 layers) and 0.86 mm blades (2 lines)
    - Scalloped rim: the backplate is cut away between neighbouring blades
    beyond r = 32 mm, keeping a 2 mm strip either side of each blade. The
    eye and inner passages keep a full floor
    - Balanced by construction (centre of mass on the axis); one valid solid,
    watertight STL; check_fit passes
    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
    [impeller.step, impeller.stl, motor_spider.step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]
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2026-09-27 Airflow analysis: impeller, ducts and air-multiplier thrusters
    Analysis/airflow.py solves the chain backwards from thrust using the CAD
    dimensions and writes Analysis/AIRFLOW.md:
    - Hover on fan thrust isn't feasible at this scale (~8.6 N needed); the
    bench demo target is controlled, vectored thrust
    - v0 (0.8 mm slot, 13 mm stem) is fan-speed-limited to about 50 gf: the
    stem chokes the flow and the slot jet is too small
    - Best feasible point: 1.6 mm slot, 22 mm stem (with the duct flared at
    its end), impeller eye r 30 mm and exit width ~13 mm, about 12,000 rpm
    (A2212 1400KV on 3S, ~150 W shaft) -> about 240 gf total (183-318 gf
    across the coefficient range)
    - Plenum sizing: the floo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
    [airflow.py]
2026-09-27 926 rev E: smooth intake, no decks, lattice outside the air path
    - Slice: the trough is gone; the skin arc rolls into the shaft over a 12 mm
    bellmouth. No decks. The fan housing shrinks to r 80 at the keel, with
    the duct mouths at r ~60; the keel is solid only under the housing and
    everything else is oval lattice with hollow diamonds and half-diamonds.
    About 32.5 cm3 (~40 g) per slice.
    - Intake shaft is now smooth: the motor ledge and spider are removed. The
    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
    [PieSlice926clauderevE.stl, airship pie slice 926.FCStd, airship pie slice 926.step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]
2026-09-27 926 bench model v0: shrouded fan housing, keel hatch, website and README
    - Slice: the fan housing is now the fan's shroud. The shaft narrows
    smoothly to the 66 mm impeller eye, and the housing wall turns over the
    blade tips with 1.5 mm clearance. This closes the leak path back up the
    shaft.
    - The keel under the fan is now a removable bayonet hatch (fan_hatch) that
    carries the 2207 and the impeller. Each slice has a lug and a stop post;
    the motor torque keeps the hatch locked. This replaces the keel pedestal.
    - Impeller: blade tops follow the shroud; eye 66 mm, exit width 12.5 mm.
    Thruster slot is 1.6 mm (the analysis optimum within the 75 m/s tip
    speed).
    - Airflow analysis: shr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
    [PieSlice926clauderevE.stl, airship pie slice 926.FCStd, airship pie slice 926.step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]
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2026-09-27 926 v0.1: 4-thruster design and a Ø66 intake
    - Narrow intake: the shaft is now the impeller eye's diameter (Ø66) all
    the way up, instead of Ø95 narrowing at the bottom. The impeller comes in
    through the keel hatch, so the wide shaft is no longer needed. This costs
    ~1% of the fan pressure and gives the gas cells ~0.6 L more room.
    - New 4-thruster design (OAS_VARIANT=4T): 4 thrusters on alternate seams,
    still on the equator. Ducts are Ø34, stems Ø34/31, rings 72 mm with a
    2.0 mm slot, gears 44T. The housing ceiling is 10 mm higher for the
    bigger duct mouths. It uses 4 left + 4 right slices (OAS_SIDE=L|R),
    alternating. Expected thrust is ~422 gf (8 thrusters: ~408 gf); see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
    [PieSlice926-v0-revE.stl, PieSlice926-v0.1-4T-left.stl, PieSlice926-v0.1-4T-right.stl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]
2026-09-27 926 v0.1.1: Kobra Max size, lightweight PLA, float budget
    - Kobra Max (x1.9, 790 mm) versions of both designs: slices print at
    372 x 393 x 279 mm on the 400 x 400 x 450 mm bed. Only the hull outline
    and lattice grow; walls, ribs, fan, ducts, thrusters and servos keep
    their size. Hydrogen volume is 124 L (bench: 16 L). All checks and the
    35 fit checks pass for both.
    - Analysis/FLOAT.md (float_budget.py + hull_volumes.py): mass, hydrogen
    lift and fan thrust for every design, size and material. 4-thruster
    Kobra Max in lightweight PLA: 624-742 g, 139 g of H2 lift (19-22%),
    67-185 g short of hovering with the fan. The bench 4-thruster in full
    foam hovers with the fan.
    - Lightweigh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
    [PieSlice926-v0.1-4T-left-KobraMax.stl, PieSlice926-v0.1-4T-right-KobraMax.stl, PieSlice926-v0.1-8T-KobraMax.stl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]
2026-09-28 926 v0.1.2: even lattice rows top and bottom, thruster-ring feed fix
    - Skin ring ribs below the equator are now spaced by equal skin length,
    like the upper rows. Before, the angle spacing left squat, wide rows near
    the equator (37-47 x ~150 mm at Kobra Max size) whose flat ovals formed
    wide solid bands. Every row is now ~33 mm (bench) / ~73 mm (Kobra Max)
    along the skin; the equator rib stays at z = 0.
    - Thruster ring: the stem feed was cut through the diffuser cone, letting
    air skip the Coanda slot. It now opens only through the outer wall into
    the plenum; a check confirms the cone is intact.
    - 4-thruster ring: same slim profile as the 8T ring (32 mm diffuser, 69 mm
    OD). The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
    [PieSlice926-v0.1-4T-left-KobraMax.stl, PieSlice926-v0.1-4T-left.stl, PieSlice926-v0.1-4T-right-KobraMax.stl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]
2026-09-29 Renders: show only the near half of the hull, so the far side's lattice doesn't show through the windows and look like overlapping ovals; add a single Kobra Max slice render
    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
2026-09-29 926 v0.1.3: minimum-material lattice
    - Ovals are laid out on the real curved skin, so each fills its cell and
    touches all four rib lines. Before, they were drawn flat at the cell
    centre and cut only 4 mm deep, so on curved skin (worst near the equator
    and at Kobra Max size) the holes came out smaller than drawn.
    - Junction windows take all the skin more than 2 mm from the ovals
    (instead of fixed diamonds), including on the first and last rows. Every
    web left is 2.0 mm; the seam edge strips stay continuous.
    - Cutters are straight projections trimmed to a thin shell round the skin,
    so they cut the skin and nothing inside it; their reach grows with the
    window size (fixes loose ski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
    [PieSlice926-v0.1-4T-left-KobraMax.stl, PieSlice926-v0.1-4T-left.stl, PieSlice926-v0.1-4T-right-KobraMax.stl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]
2026-09-29 926 v0.2: self-contained double-Kobra build that floats (#34)
    - 12 slices (left, right, plain) at x3.8 (1.58 m), each cut into 5 pieces
    that fit a Kobra Max, with pegs across every cut and ribs on every cut line
    - Intake shaft as two printed tubes; 1.2 mm lattice webs; 4 thrusters with
    8T-size ducts and rings; SG90 servos
    - Avionics tray on the intake tube for battery halves and electronics
    - Firmware: direct PWM on the ESP32, 4-thruster layout, battery monitor,
    cross-coupling-free mixer
    - Float budget: 903 g all-up (full-foam LW-PLA, 1500 mAh LiPo) against
    1145 g of hydrogen lift in 1022 L; every option floats
    - Fixes: retry window cuts the kernel skips, joint bosses clear of the sk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
    [PieSlice926-v0.2-intake-tube-1.stl, PieSlice926-v0.2-intake-tube-2.stl, PieSlice926-v0.2-left-bottom-inner.stl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]
2026-10-03 1026 v0.2.1: flush fan housing, lighter keel, corrected float budget (#35)
    - Thrust ducts hug the hull curve from their mouths and run straight on
    from the fan housing: the ceiling eases down to the duct tops, the keel
    is the floor, the outer wall stands at the mouths, and the duct wall is
    trimmed to the housing's inside shape (no lip, no gap; leak-tested)
    - First lattice rib sits at the housing wall (it was ~13 mm out on the
    flat keel), so ovals and diamonds reach the housing; hull 4-7% lighter
    - Double Kobra: first-row junctions laid out on the unrolled skin (the flat
    tangent plane cut a web loose near the axis)
    - Float budget: fall back to the kernel volume for non-watertight me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
    [PieSlice1026-v0.2.1-4T-left-KobraMax.stl, PieSlice1026-v0.2.1-4T-left.stl, PieSlice1026-v0.2.1-4T-right-KobraMax.stl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]
